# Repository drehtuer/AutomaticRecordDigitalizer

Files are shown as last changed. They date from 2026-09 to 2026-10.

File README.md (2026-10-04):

# AutomaticRecordDigitalizer






A DIY machine that digitises a vinyl record collection unattended: it takes a record from a magazine, puts it on a Technics-style turntable (an Omnitronic DD 3120), cues the stylus, records the side, flips the record, records the other side, and puts it back — 10 to 20 records per eight-hour run, a full 24-slot magazine over a weekend, with a photo of both labels for the tags. Records are brushed by hand before they go into the magazine.

The project exists because the cheap way of doing this, a second-hand stacking record changer, drops records onto each other and the recordings show it. Here nothing ever touches a record except a vacuum cup on the label, the slot it stands in, and the turntable mat.

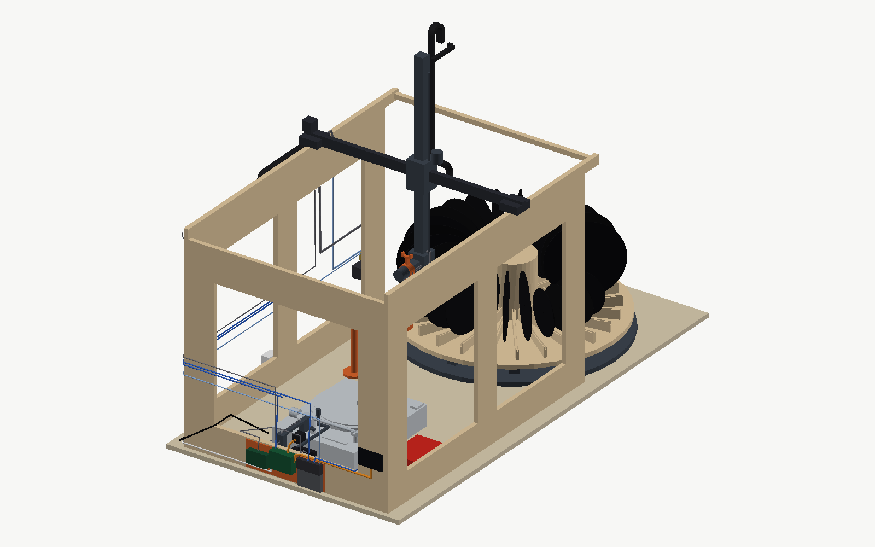
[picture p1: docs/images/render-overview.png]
The machine, rendered from the CAD model: the carousel of records on the left, the gantry on its wooden frame, the turntable on the right, the electronics on the outside of the panels


## Status

Concept design finished and reviewed in September 2026; first parametric CAD in place, with the whole cycle passing a scripted collision check. Nothing has been bought or printed yet. [docs/07-status-and-next-steps.md](docs/07-status-and-next-steps.md) records exactly where the project stands, what is already on hand, and what to do first.

## What is in this repository

[cad-model.html](cad-model.html) is the machine in the browser: orbit and zoom it, play the cycle for a 12", a 10" or a 7" record, or jump to any of the fourteen steps. Both halves come from the parametric model — the geometry from `python -m cad.export_web`, the motion from the planner's own keyframes in `cad/cycle.json`, one cycle per record size — so it shows the machine the collision checker sweeps, moving the way it sweeps it. The carousel carries a mixed load of all three sizes, with the empty slot the loading rule asks for.

[concept-model.html](concept-model.html) is an interactive 3D model that steps through the complete operating cycle, including the B-side flip and the fault case, with every step's motion planned as real waypoints in the order the controller will use. Its geometry is its own, written during the concept phase, and predates the five corrections the CAD found: read it for the sequence, not for dimensions.

`cad/` is the parametric CadQuery model with the motion planner and the collision checker; `cad/README.md` explains how to run it, and `cad/export/` holds STEP files that open in FreeCAD, STL files of the first printed parts, and `web/` holds the glTF and the scene description the viewer loads.

`sourcing/` is the pricing pass of September 2026, re-verified on 3 October: every line of the bill of materials against live German shop pages, with product links, three ways of ordering it and a sheet for the local Baumarkt, and the corrections it forced back into the design documents.

`docs/` holds the design in detail:

| Document | Contents |
|---|---|
| [01-design-specification.md](docs/01-design-specification.md) | Mechanical layout, every subsystem, dimensions, materials |
| [02-operating-cycle.md](docs/02-operating-cycle.md) | The cycle step by step, motion-planning rules, fault handling |
| [03-electronics-and-software.md](docs/03-electronics-and-software.md) | Controller, wiring, Klipper, orchestrator, vision, web UI, recording |
| [04-bill-of-materials.md](docs/04-bill-of-materials.md) | Parts with German sources, printed-part list, cost |
| [05-design-decisions.md](docs/05-design-decisions.md) | Why the machine is the way it is, including rejected alternatives |
| [06-open-questions.md](docs/06-open-questions.md) | What has to be verified on real hardware |
| [07-status-and-next-steps.md](docs/07-status-and-next-steps.md) | Current state, parts on hand, build order |
| [08-assembly-instructions.md](docs/08-assembly-instructions.md) | Cut list, Baumarkt list, printed parts, assembly order, cable lengths |

## The machine in one paragraph

Records stand like spokes in a 24-slot carousel. A small XYZ gantry with a rotary wrist carries a vacuum cup that takes each record by its label, lifts it out of its slot, turns it flat over the deck and sets it on the spindle. The deck's own cue lever, worked by a servo, lifts the tonearm while a fork on the wrist walks it to the lead-in groove found by a camera; the platter is stopped before every needle placement and removal. After the run-out, the record goes to a ring rest where the cup lets go and re-grips the other face, both labels get photographed, and side B is recorded the same way. The record returns to its own slot and the carousel indexes to the next one. The deck's remote start/stop connector starts and stops the platter. Recording runs through a Focusrite Scarlett into a Raspberry Pi, which also runs the cameras, the web interface for the batch list, and the orchestration on top of Klipper running on a printer mainboard, with a USB relay card working the deck's remote start/stop jack and speed buttons.

## Follow-up project

Cutting the recordings into tracks, mastering, and tagging (using the label photos and the batch manifest) is deliberately out of scope until the changer has proven itself on real records.

## License

Copyright (C) 2026 drehtuer

This project is free software; you can redistribute it and/or modify it under the terms of the GNU General Public License as published by the Free Software Foundation; either version 2 of the License, or (at your option) any later version. The text of version 2 is in [LICENSE](LICENSE); the SPDX identifier is `GPL-2.0-or-later`.

It is distributed in the hope that it will be useful, but WITHOUT ANY WARRANTY; without even the implied warranty of MERCHANTABILITY or FITNESS FOR A PARTICULAR PURPOSE. See the GNU General Public License for more details.

The licence covers everything here: the CadQuery model and the planner as source code, and the design documents and the concept model as the machine's design.

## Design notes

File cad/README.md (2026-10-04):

# CAD

Parametric CadQuery model of the machine, the motion planner of the cycle, and a collision
checker that sweeps every step of the cycle against the whole machine.

```sh
pip install cadquery            # 2.4 or newer; pulls in the OpenCascade kernel
python -m cad.check_collisions  # sweep the full cycle with a 12", then the pick with a 10" and a 7"; exit 1 on any intersection
python -m cad.check_collisions --size 7   # the whole cycle with a 7"
python -m cad.assembly place regrip   # STEP of the whole machine at named poses
python -m cad.export_parts      # STL of the printed parts, STEP of the sub-assemblies
python -m cad.kinematics > cad/cycle.json  # the keyframes of the cycle for every record size, keyed "12", "10", "7" (--size 7 for one, as a bare list)
python -m cad.export_web        # glTF of every rigid body plus scene.json, for cad-model.html
python -m cad.render            # PNG views of the machine at rest into docs/images/, for the documents
python -m cad.render --animate  # the cycle for every record size as animated PNG, into docs/images/
```

Run the commands from the repository root.

## Layout

`params.py` holds every dimension in millimetres, including the deck measurements marked
MEASURE that still have to be confirmed with a ruler; the deck's outline, platter height,
spindle, arm pivot and cue-lever travel are measured. Change a number there and everything
downstream follows.

`parts/` builds the solids: `deck.py` (plinth, platter, tonearm as a rigid body pivoting about
the measured pivot, cue lever), `carousel.py` (base with roller ring, rotating disc with hub,
V-floor combs and tooth ring, records of any size as spokes), `frame.py` (plywood box, V-slot beams, flip
station on its foot), `gantry.py` (X, Y and Z carriages and the wrist with cup, camera and
fork, each in its own kinematic frame), `deck_interface.py` (cue-lever servo on its beam with
horn and yoke, the end stop, deck camera and LED bar), `electronics.py` (every board and box on the frame
at its catalogue size, the three cable chains, and the cable and hose runs as tubes along their
routes). The chains and the cables that feed them are drawn at the home pose, because their shape
changes with every move; the sweep checks the electronics and the cable runs that ride rigidly on
the column and the wrist, and does not check the chains.

`kinematics.py` is the forward kinematics (where the cup and the fork are for a carriage
position and wrist angle), the fourteen poses of the cycle, and the planner that turns two
poses into a list of keyframes: retreat, raise, ordered horizontal moves, lower, approach, with
the special plans for the station and the tonearm steps. It is the same planner the concept
model animates and the one the orchestrator will run.

`assembly.py` places the parts for a state and exports a coloured STEP. `check_collisions.py`
samples every keyframe segment (20 mm and 5° by default), rebuilds the moving parts and the
pose-dependent environment (tonearm angle and lift, carousel angle, which records are where)
and reports every intersection between the Z carriage, the wrist and the held record and
anything else, with the pose, the segment and the position. `export_parts.py` writes the STL
files for printing and the sub-assembly STEP files for FreeCAD. `export_web.py` writes every rigid body in
its rest frame as one glTF plus `scene.json`, the constants the viewer in `cad-model.html` needs to assemble
and animate them; the viewer restates no dimension of its own. `render.py` tessellates the machine and rasterises
orthographic views through a depth buffer with nothing but numpy, since the container has no renderer and
no browser; the pictures in the documents come from it, and with `--animate` it samples the planner's
keyframes on the web viewer's own timeline and places every rest-frame part exactly as the viewer does
(checked: the same bounding boxes as `Machine` to the last millimetre), writing one animated PNG per size.

`export/` holds generated files. They are committed at reviewed states so the STEP files can
be opened without running anything; regenerate them after changing `params.py`.

## Coordinate system

X along the bench from the carousel towards the deck, Y across the bench with +Y towards the
front, Z up. Origin on the bench top, 200 mm left of the flip station post, on the machine's
centreline. A carriage state is the centre of the Z carriage block; the wrist pivot sits
`WRIST_X` further along +X. Wrist angle `phi` is a right-hand rotation about +X: 0 is the arm
hanging with the cup facing −Y, +90 is the cup facing down, −90 the cup facing up, 180 the arm
pointing up with the fork pointing down.

## Record sizes

Every record stands with its centre at `CAR_REC_R`, whatever its diameter, because the slot floor
of each comb is a V with its apex there; `carousel.record_z(r)` gives the centre height for a
radius. `Machine(record_r)` builds the machine with a record of that radius in slot 0, on the cup,
on the platter and on the ring, with 12" records in the other slots, and `kinematics.full_cycle(r)`
plans the cycle for it: only the pick and the return move. `Machine(load=carousel.DEMO_LOAD)` fills the
other slots with the mixed load the pictures and the viewer show (three 10", four 7", one empty slot for
the loading rule, 12" in the rest); the checker never uses it. The neighbour that matters is slot 1,
the spoke on the front side of the pick, the one the wrist descends beside; `Machine(record_r,
neighbour_r)` sets it (None leaves it empty). The checker sweeps the whole cycle with a 12" and then
the pick, the carry away from the slot and the return with a 10" beside a 12" and a 7" beside a 10",
the largest neighbours the loading rule allows; `--size 7 --neighbour 12 --poses pick` shows why the
rule exists.

## Fidelity

This is a layout model: every part has its true envelope, position and travel, the records are
real discs with holes, and the tonearm pivots about the measured point. It is not yet a print
model. The printed parts that exist as separate functions (`comb`, `hub`, `roller_bracket`,
`ring_rest`, `fork`) have their functional features; the rest of the printed parts are still
envelopes inside their sub-assembly and get detailed as the build reaches them.

## What the checker found so far

Running the checker on the first version of this model found five real problems that the
concept model had not shown, and they are fixed here: the wrist camera on the hub side of the
arm sat where the gap between spokes narrows (moved to the outer side and higher up the arm);
the cup bracket reached below the cup and met the spindle tip (raised); the end-stop pin stood
inside a 12" record's outline (moved from 60 to 45 mm from the pivot); the fork pointed through
the rear panel at the re-grip pose (shortened from 100 to 55 mm, frame widened to 86 cm); and the
swing to B-up over the deck pushed the record into the front panel (the station plan now swings
the record to vertical before moving Y). Adding the record sizes found a sixth: picking a 7" beside
a 12" puts the wrist hub 18 mm and the column's foot 7 mm into the neighbour, which no change to
the slot can fix and became the loading rule in the design decisions. At 20 mm / 5° sampling the
cycle runs with zero intersections for every size.

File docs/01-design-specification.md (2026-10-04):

# Design specification

This document describes the machine as it stands after the concept review. Dimensions are the ones used in the concept model and are good to a centimetre; the CAD phase fixes them to the millimetre. The coordinate system is the machine's: X runs along the bench from the carousel towards the deck, Y runs across the bench (positive towards the front), Z is up. The origin is at the bench top under the flip station.

## Overview and footprint

The bench is about 190 × 100 cm. From left to right it carries the carousel magazine (Ø 86 cm, standing free on the bench), then the frame (121 × 88 × 83 cm over the panels) that spans the flip station and the turntable. The gantry rides on top of the frame; its Z column rises to about 135 cm when fully raised, so the machine wants a metre and a half of headroom.

The frame's left end is open and its X beams overhang it by 8 cm so that the gantry can reach the carousel's pick slot, which is the only point where the two halves of the machine meet. The carousel can be lifted off the bench for loading without touching the frame.

## Frame

The frame is a glued box of 18 mm OSB 3: two side panels at Y = ±43 cm and one end panel at the deck end, each cut as a frame around a large window so the interior stays open and reachable. The panels give the racking stiffness; there are no diagonals, and the only corner posts are a steel angle down each inside corner where the side panels meet the end panel, because a screw into an OSB edge holds poorly. A 2040 V-slot extrusion is bolted along the top edge of each side panel and is the X axis: the carriages run on Delrin V-wheels in the slot, as on a hobby printer. One 2020 tie across the open end keeps the two beams parallel. Brackets for the cue-lever servo, the deck camera and the LED bar fix directly to the panels' inner faces, on M4 T-nuts wherever a part has to come off again.

The electronics are not boxed: the controller board and its supply mount on the outside of the rear panel under the X beam, the pump and valve on the same panel near the open end, and the Pi with its USB devices on the outside of the deck-end panel. The flip station's post stands on a printed foot on the bench.

## Gantry

The gantry is a Cartesian XYZ with one rotary axis:

| Axis | Mechanism | Travel | Notes |
|---|---|---|---|
| X | GT2 belt, NEMA17, Delrin wheels on 2040 V-slot beams | ≈ 80 cm | From the carousel pick slot to the tonearm rest |
| Y | GT2 belt, NEMA17, Delrin wheels on a 2040 V-slot cross beam | ≈ 63 cm | The concept assumed 45 cm; the planner's re-grip poses reach from −34 cm to +28.5 cm. The 94 cm cross beam gives about 70 cm; the frame is 86 cm wide so the fork clears the rear panel at the re-grip pose |
| Z | T8 lead screw, NEMA17, moving column on an MGN12 rail | ≈ 60 cm | Column slides through a guide on the cross beam; self-locking; the one axis that keeps a linear rail |
| Wrist | NEMA17 with ≈ 5:1 planetary gearbox, Hall home sensor | −90° … 180° | Axis parallel to X |

The Z axis is a moving column rather than a fixed tower: the 76 cm rail is part of the carriage and slides up through a guide block on the cross beam, so when the carriage is raised nothing hangs below it. Every X move happens at travel height and clears the deck and the station by construction. The lead screw is self-locking, so a power loss leaves the record where it is.

The wrist sits on a 9 cm outrigger beside the column so the arm can swing without meeting it. It carries three things: the vacuum arm (22 cm, with the cup on its end pointing perpendicular to the arm), the wrist camera looking along the cup's axis, mounted on the outer (+X) side of the arm 11 cm up from the cup, and the finger-lift fork on the opposite side of the hub, 5.5 cm long, which points down when the arm points up. The cup bracket does not reach below the cup, so the spindle tip, which enters the hollow bellows cup when a record is released over the spindle, meets nothing.

## Gripper

The gripper is a single 40 mm bellows vacuum cup on the label area, fed by a 12 V diaphragm pump through a solenoid release valve, with a pressure sensor on the line that confirms a seal before any move and aborts a move if the seal is lost. The label area is the one thing every record has in common, so the cup handles 12", 10" and 7" records and shaped discs alike; 7" singles with the large jukebox hole are out of scope. What the cup can hold and what the carousel can present are not the same set: the magazine locates a record by its round edge, so a shaped picture disc, or one whose outline is not centred on its hole, is placed on the platter by hand and the machine does the rest (see the operating cycle).

The cup's bellows give about 5 mm of compliance, which is what lets the cup land on a spoke standing slightly off its nominal position. At the pick position the cup stops 8 mm short of the record's face and makes the last 8 mm as a slow approach; the gap between spoke faces at the arm's radius is 65 mm and the cup-to-arm-back assembly is 48 mm, so the approach and a 9 mm margin use the rest.

## Carousel magazine

The magazine is a horizontal disc with 24 radial slots at 15° pitch. Records stand vertically in the slots like spokes, each in a 5 mm slot on top of a printed comb. The floor of that slot is a shallow V, sloping 5° each way from an apex 26 cm from the axis, so a record of any diameter rolls to the apex and stands with its centre on the same vertical line: 12", 10" and 7" records all sit at the same radius, and only the height of the centre differs, by the record's radius. The pick is therefore the same X and Y for every size, and the machine takes the height from the size in the batch manifest. At that radius the gap between neighbouring spokes is about 6.5 cm face to face, enough for the 5 cm gripper assembly to descend beside a record. A 10" is picked 25 mm lower between the same neighbours, through the same gap. A 7" is picked 62 mm lower, and there the gap runs out: the wrist hub, the outrigger and the foot of the column sit 22 cm above the cup and are wider than the gap at the radius where they descend, so they have to stay above the top edge of the neighbouring spoke on the front side, the side the wrist hangs on. Beside a 12" neighbour a 7" pick puts the hub 18 mm and the column's foot 7 mm below that edge. So the slot on a 7"'s front side holds a 7", a 10" or nothing, a rule the manifest editor enforces; a run of 7"s costs one empty slot at its front end. There is no rim: the V does the locating, and a wall tall enough to touch every size at its own centre would stand in the way of a record being carried past at travel height.

The disc is 18 mm MDF cut roughly round and is nothing but a floor. It rolls on ten identical printed brackets, each holding a 608 bearing, arranged on a 72 cm circle, and is located by a 6005 bearing on a stub shaft at the centre. A printed GT2 tooth ring in eight dovetailed segments on the disc's underside is driven by a NEMA17 with a 20-tooth pulley, about 34:1 at the ring and about 170:1 with the motor's 5:1 gearbox, and an optical sensor reads a home mark; one slot index is therefore repeatable to a fraction of a millimetre at the rim. The 24 slot combs plug into a printed centre hub, which carries the angular positions, and are screwed to the disc at their outer ends, so the wood never has to be cut precisely.

Each record returns to the slot it came from, so the magazine is both infeed and outfeed, records never touch each other, and pick and return happen at one fixed position: the slot that points along X towards the deck.

## Flip and photo station

A ring rest on a post 12 cm behind the machine's centreline, at X = 20 cm, Z = 30 cm: a printed ring of 100 mm mean diameter and 6 mm section, so it contacts a record between 44 and 56 mm from its centre — the edge of the label, where the record is stiffest — with a 3 mm rubber O-ring in a groove on top that the record actually rests on. It holds a 7" with 32 mm of overhang, leaves 16 mm between the cup and its inner edge, and its 60° opening towards the front, 44 mm wide at the inner edge, passes the 24 mm arm with 10 mm a side. That the ring touches a 12" just outside the label is accepted: the O-ring is soft, and stability matters more than the last millimetre of dead wax. The station is deliberately off the centreline so that a vertical record travelling along X at travel height passes beside it.

## Turntable interface

The deck is an Omnitronic DD 3120: a Technics-type direct drive, 44.9 × 35.1 × 8.6 cm as measured, from the feet to the top of the case, with the platter standing 1.8 cm above that, with a manual cue lever, a remote start/stop connector, a pitch output, 33/45/78 rpm with quartz lock and ±10/±20 % pitch range, and no auto-return. Measured on the deck: the spindle sits 17.9 cm from the left edge and 17.4 cm from the rear edge; the arm pivot, the screw on top of the bearing, is 6.95 cm from the right edge and 9.35 cm from the rear, which puts it 20.05 cm to the right of and 8.05 cm behind the spindle (pivot-to-spindle 21.6 cm, a 14 mm overhang on a 23 cm effective length); the top of the cue lever is 4 cm inside the right edge and travels front to back, from 14.6 cm from the rear edge with the arm down to 12.2 cm with the arm lifted, 24 mm towards the rear. Still from a top-down photo (`images/dd-3120-top.jpg`) and to be confirmed with a ruler: the arm rest is about half a centimetre left of and 21 cm in front of the pivot; start/stop and the speed buttons are at the front left, the power knob at the left, the pitch fader at the right in front of the arm, and the deck's own red strobe LED shines on the platter rim at the front left. The platter rim carries four rows of strobe dots.

The felt DJ slipmat in the photo should be replaced by a rubber or cork mat for digitising: a slipmat is made to let the record slip, and it also holds static and dust. (A Stanton T.92 USB is also available but has no cue lever, which would bring back a separate arm-lift mechanism; it stays the spare.) The cartridge is an Ortofon DJ S, a spherical DJ stylus tracking at about 3 g, robust against the kind of handling this machine does; an elliptical stylus can be swapped in for a final archive pass once the machine is trusted. The machine touches the deck in four places, none of them modifications:

Start and stop go through the deck's own remote start/stop connector, a 6.3 mm jack made for the fader-start feature of older mixers and hi-fi systems, which started the deck when the fader came up: it expects a contact closure and does nothing but start and stop the platter (speed is chosen with the buttons). One channel of the Conrad 393905 USB relay card (already on hand, driven from the Pi) on a 6.3 mm plug does it, with no wire soldered inside the deck. The 33 and 45 buttons are momentary switches and are pressed by two more channels of the same card wired across the switch contacts inside the deck; a relay is a dry contact, so polarity and the switch's voltage do not matter.

The cue lever is worked by an MG996R servo that hangs over it from a beam off the deck-end panel of the frame. The lever's top travels 24 mm front to back, so a rod pushing along X from the panel cannot move it; the servo's shaft stands vertical 28 mm to the right of the lever, and its horn carries a yoke that straddles the lever's top and takes it both ways, about 25° of horn either side of the middle. The lever is 4 cm from the deck's right edge, so the servo sits over the edge of the case, to the right of the arm base and outside the arm's swing. A bar from a foot on the same panel runs in front of the lever, under the arm, and carries a soft-sleeved end-stop pin standing in the arm tube's path 45 mm from the pivot, so the arm cannot swing past a stylus radius of roughly 53 mm: the stylus physically cannot reach the label. At 45 mm the pin stands outside a 12" record's outline; at the 60 mm first drawn it stood under the record's edge.

The tonearm is moved only while the cue lever holds it up, by the fork straddling the headshell's finger lift with prongs fore and aft of it. The fork never carries the arm's weight.

The arm rest clip stays open.

## Cleaning

There is no cleaning module. Records are brushed by hand before they go into the carousel; a brush pass takes a minute per record and is the right moment to look each one over anyway. A frame-mounted brush with a dust edge was designed and dropped as a simplification; the decision log has the details, and the rear panel has room for it if it ever comes back.

## Cameras and light

The wrist camera (a USB webcam, a Logitech C270) sits on the outer side of the wrist arm, 11 cm up from the cup, looking along the cup axis. With the cup pointing down it looks straight down, and that is where it works: hovering over the platter after a record is placed it photographs the label that is facing up, finds the centre (the spindle is in the hole) and measures the lead-in and run-out radii; over the ring rest it photographs the other label before the re-grip. Both label photographs come from it, each taken face-on with nothing in the way. At the carousel it does not look at the record: inside the 65 mm gap between spokes there is no room for a camera at a usable distance, and none is needed, because a record that has rolled to the apex of its comb's V has its centre within a millimetre of a known position, which the cup's bellows and the spindle tip absorb.

The deck camera (Pi Camera Module 3) is mounted low on the deck-end panel at platter height, facing the headshell across the platter from 20 to 40 cm. It sees the stylus in profile, the groove bands edge-on and the strobe dots on the platter rim. It tracks the headshell to locate the arm wherever a side ended, confirms the stylus landed on the lead-in, watches for the run-out and for skips, and reads the platter speed.

An LED bar beside the deck camera has two modes: pulsed at 50.000 Hz from the controller's crystal it is a strobe that makes the rim dots (or a printed strobe ring on a deck without dots) show the speed error as a drift; run continuously it is a low-angle raking light that makes the grooves and the stylus contact visible.

## Materials and printing

Printed parts are PETG for structure and TPU wherever a record is touched: the cup lip if not bought, the fork lining, the end-stop sleeve; the ring rest carries a bought rubber O-ring instead. Bought parts are everything long, stiff or precise: extrusion, the Z rail, screws, bearings, motors, electronics; a used 3D printer is the intended source for most of the motion parts. Plywood is used for the frame panels, the bench top, the carousel disc and its base plate, and never for anything whose position matters.

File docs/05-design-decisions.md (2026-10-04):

# Design decisions

The machine took its shape through a review of a series of concept models. This document records what was decided, why, and what was rejected, so the reasoning survives into the CAD and software phases.

## No stacking changer

A second-hand automatic changer costs a fraction of this machine and needs no building. It was rejected because it drops each record onto the previous one, and a record playing on a stack of records is tilted, poorly supported and audibly distorted. Every other decision follows from the requirement that a record is never supported by anything but the mat, and never touched except on its label.

## Gantry, not an arm

A Cartesian gantry with one rotary wrist was chosen over an articulated arm. Linear axes give repeatable positioning for free, a 3D-printed jointed arm is hard to make stiff, and a gantry turns the whole build into a printer-shaped problem with a printer's toolchain. The wrist is the only joint and it does two jobs: turning the record from vertical to horizontal and flipping it for side B.

## Vacuum cup on the label

Early concepts gripped the rim with three fingers. That failed on two requirements: 10" and 7" records have a different rim, and shaped records ("sawblades") have no usable rim at all. The label area is the one feature common to every record, so the gripper is a single vacuum cup on the label. A label-pinch gripper (a pin through the centre hole and a jaw on the label) was considered as an alternative that needs no pump and cannot drop a record when power fails; it was set aside because the vacuum cup is simpler and a sensor on the line gives a positive confirmation of grip (the switch first drawn became a pressure sensor; see below). 7" singles with the large jukebox hole are excluded.

## Round magazine instead of racks

The first layouts had a leaning queue for infeed and a slotted rack for outfeed, later a stepper-driven follower and a slotted comb. Each had a flaw: the queue put records face to face under pressure, the slotted rack could not accept a record with the gripper beside it at 20 mm pitch, and both needed the gantry to travel over 1.5 m. A round magazine with records as spokes solves all of it: the gap between neighbours at the label is 6.5 cm, pick and return are at one fixed position, each record goes back into its own slot, records never touch, and the X travel halved. The price is a diameter of 86 cm.

## Every size at one radius: the V floor

The concept placed records with their outer edge against a rim ring, so that every size would sit at the same outer radius and a 7" would stand where the gap between spokes is wider. The first CAD drew the ring and never used it: a ring at one height meets a 12", a 10" and a 7" at three different chords, so each size would have come to rest at its own radius, and the pick was in fact drawn for a 12" alone, standing on the disc through its comb. A wall tall enough to touch every size at its own centre, 17 cm above the disc, would stand in the way of the carried record, whose lower edge passes 7 cm above the disc at travel height. The rim is gone. Instead the floor of each comb's slot is a shallow V, 5° each way, with its apex 26 cm from the axis: a record of any diameter rolls to the apex and stands with its centre on one vertical line, and only its centre height differs, by its radius. The pick and the return are the same X and Y for every size, with the height from the manifest's size; the planner and the collision sweep take the size as a parameter, and the sweep runs the 10" and the 7" through the pick, the carry away from the slot and the return, between 12" neighbours. The 7" gives up the wider gap the rim would have given it, and the sweep showed where that bites; the next entry is the answer.

## A 7" wants a 7", a 10" or nothing on its front side

The first sweep with a 7" in the pick slot and 12" records around it found the wrist hub 18 mm and the foot of the column 7 mm inside the neighbouring spoke on the front side, the side the wrist hangs on. The geometry is simple: everything at the wrist pivot sits 22 cm above the cup, a 12" neighbour's edge reaches 15 cm above its own centre, and a 7" is picked 62 mm deeper than a 12", so the pivot hardware ends up 8 mm below that edge and its own height does the rest; at the radius where the column's foot descends the gap between spokes is 42 mm, which no column with a lead screw beside it fits. Nothing passive in the slot helps, because a floor that lifts a small disc lifts a large one at least as much. A 3 cm longer arm would lift the hub clear but pushes the re-grip pose past the Y travel unless the station moves 3 cm towards the centreline, with everything that follows from that; a hub small enough to fit would have no room for its bearings; a saddle dropped into the slot under each 7" would work until someone forgot one. The rule costs nothing: the slot on a 7"'s front side holds a 7", a 10" or nothing, so a run of 7"s costs one empty slot at its front end, and the manifest editor refuses a batch that breaks it. The collision sweep runs the 7" with a 10" in front of it, the largest neighbour the rule allows, and `python -m cad.check_collisions --size 7 --neighbour 12 --poses pick` reproduces the case it forbids. A 10" needs no rule: beside a 12" it keeps 19 mm at the hub and 32 at the column's foot.

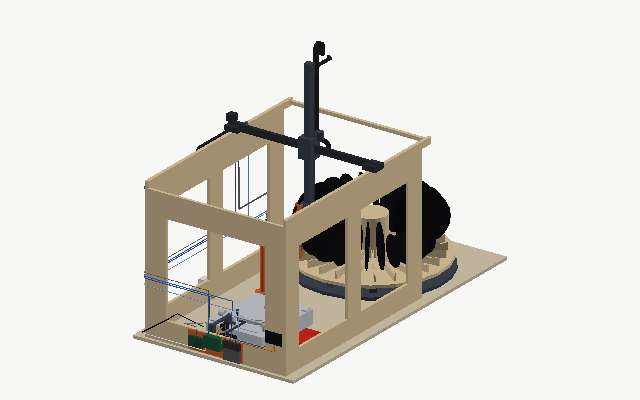
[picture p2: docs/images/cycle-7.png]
The cycle for a 7" record, rendered from the model: the wrist descends 62 mm deeper into the carousel than for a 12", beside the 10" the loading rule allows there


## Shaped and off-centre discs are placed by hand

The V locates a record by its round edge, and the pick assumes the label at the centre of that circle. A shaped picture disc has no round edge to roll on, and a disc whose outline is not centred on its hole stands at a height the machine cannot know; the cup could hold either by its label, but the machine could not find the label, and one look with the wrist camera cannot help, because there is no room for it inside the gap. Rather than an adapter or a special slot, the manifest has a "by hand" line: the gantry parks, the user lays the record on the spindle, and the machine records the side, photographs and measures it, and waits for the user again at the flip and at the end. The cycle is unchanged, the carousel is untouched, and a mode the machine needs anyway for a record too precious to be picked covers every outline the V cannot.

## Wrist axis along X

With the pick slot pointing along X, the record's face is normal to Y and the cup must approach along Y, so the wrist rotates about X and the Y axis does real work: it carries the cup onto and off the spoke and it reaches 22 cm either side of the station ring for the two station poses. This set the Y travel at about 45 cm.

## Flip via a passive ring rest

A cup on one face can never place the record with that face down; somewhere the cup must change sides. Two ways were considered: a two-cup yoke that flips in the air, and a passive ring rest that the record is set down on by its label so the cup can re-grip from the other side. The ring won because it has no moving parts, it is also the best place to photograph label B, and it costs twenty seconds per side. It was moved 12 cm off the centreline once the motion planning showed that a vertical record travelling along X would otherwise pass through it.

## Moving Z column

The first gantry had a fixed Z tower hanging from the cross beam, and it swept through the brush, the platter and the station on every X move. Replacing it with a column that slides up through a guide means nothing hangs below the carriage when it is raised, and every X move happens at a travel height that clears everything by construction.

## Fork on the wrist, opposite the arm

Hanging the finger-lift fork from the carriage either dipped it into the carousel during a pick or parked the carriage a few centimetres above the tonearm while cueing. Mounting it on the wrist hub opposite the vacuum arm means it points down exactly when the arm points up, shares the cup's Y position, and keeps the carriage well above the arm.

## The deck's own cue lever does all lifting

The turntable has a manual cue lever. A servo on a frame bracket works it, so every lift and lower of the tonearm happens on the deck's damped mechanism, and the fork only ever moves the arm sideways while it is floating. The arm cannot be dropped by the machine. The servo was first drawn at the end panel with a pusher rod along X; measuring the deck showed the lever's top travelling 24 mm front to back, which a rod from that side cannot push, so the servo now hangs over the lever on a beam from the panel, shaft vertical, with a yoke on its horn around the lever's top. The yoke moves the lever in both directions, so it does not matter whether the lever holds its position by itself. The platter is stopped before every stylus placement and removal, as it would be by a careful person; the lead-in silence absorbs the spin-up.

## Inner end stop

The cue-servo bracket initially collided with the arm's inner swing. That collision became a feature: a soft-sleeved pin on the bracket stands in the arm tube's path just past the run-out radius, so whatever the software does, the stylus cannot reach the label.

## Omnitronic DD 3120, not the Stanton T.92

Two decks were available. The Omnitronic has a cue lever, a remote start/stop jack and a pitch output; the Stanton has none of these and a built-in USB converter that is not wanted. The cue lever alone decides it: without one, the machine would need its own damped arm lift, which is the part most likely to damage a record. The remote jack (6.3 mm, the fader-start input of older mixers and hi-fi systems, start/stop only) is a bonus that removes all soldering on the start/stop switch. The cue lever turned out to sit at the front-right of the arm base, 4 cm from the deck's right edge, which put the cue servo on a short beam from the frame's end panel instead of an outrigger from the rear.

## No automatic skip recovery

A skip is detected by audio and by camera at once. The response is to lift the arm via the cue lever within half a second, stop the platter, pause the batch and notify. Re-cueing automatically was rejected because a record that skipped once will usually skip again at the same place, and an unattended retry loop grinding a stylus into a scratch is the one thing the machine must never do.

## Two cameras, placed by what they need to see

An overhead camera cannot see a label or hole past the gripper. So the label camera rides on the wrist looking along the cup's axis: with the cup pointing down over the platter or the ring rest it looks straight down at whichever label is facing up, with nothing in the way, and measures the groove radii there. The deck camera sits low at platter height facing the headshell, where it sees the stylus in profile, the groove bands edge-on and the strobe dots on the rim. A rail-top camera above the deck was tried and moved for that reason. The wrist camera was first meant to look at the record's face inside the carousel gap as well; the CAD showed there is no room for a camera at a usable distance inside a 65 mm gap, and the V floor of the comb makes the record's position known well enough that no look is needed there.

## 33/45 by the deck's buttons, not by resampling

Recording everything at one speed and resampling later was rejected because the phono stage applies RIAA equalisation at fixed frequencies; a record played at the wrong speed is equalised wrongly and resampling does not undo it. The deck's 33 and 45 buttons are momentary switches, so two relay channels across the switches and a manifest column solve it properly; relays rather than optocouplers because a dry contact needs no knowledge of the switch's polarity or voltage, and the Conrad 393905 USB relay card already on hand supplies them from the Pi.

## LED strobe for speed, not camera frame rate

The camera cannot imitate a 50 Hz neon strobe, but an LED pulsed at 50.000 Hz from the controller's crystal makes the deck's dot rows, or a printed strobe ring on a deck without them, show the speed error as a drift the camera can measure. It works on any turntable, and the same LED run continuously is a raking light that shows the grooves for cueing and stylus checks. The measured speed and wow are logged with each recording rather than corrected live.

## No brush

A frame-mounted brush with a servo arm, a dust edge and a slide-out tray was designed in full and then dropped. Brushing by hand before loading takes a minute per record, is a natural moment to inspect each one, and removes a motor, a bracket, a cycle step and a source of dust inside the machine. The rear panel keeps room for the module.

## Manual deck, not an automatic one

A fully automatic turntable would have removed the cue servo, the fork, the end stop and most of the deck camera's job, and was proposed as the biggest available simplification. It was rejected because the collection contains records an automatic deck cannot play: sides with several locked grooves, sides cut from the inside out, and records with non-standard start and end positions. Those need a machine that decides where the stylus goes and when it leaves, which is why the manual DD 3120, the fork, and both cameras stay.

## V-slot instead of linear rails

X and Y run on 2040 V-slot with Delrin wheels, as on a hobby printer, instead of MGN rails. The accuracy needed at the cup is set by the hole camera and the spindle tip, well within what V-wheels give, and the change saves about a hundred euros and makes alignment easier. The Z column keeps a rail because it carries the record vertically and its guide block must not rattle.

## A used printer as parts donor

Most of the motion parts (steppers, PSU, belts, pulleys, wheels, a lead screw, end-stops, a Klipper-capable board) come cheapest as a used 3D printer; a CR-10 class machine is the best fit because of its long extrusions and lead screws. Only the two long X beams and the Z rail are bought new.

## Wooden frame, extrusion beams

A full aluminium extrusion frame was replaced by a glued box of 18 mm sheet material with 2040 V-slot extrusion only where the X axis needs a straight, adjustable running surface. The panels give more racking stiffness than a lattice with diagonals, the interior stays open, brackets fix straight to the panels, and extrusion drops from ten metres to four. Cost is about the same; the choice is about the tools the builder prefers.

The panels are OSB 3, decided on 4 October 2026. Birch multiplex was the plan, but the only birch sheet large enough for all three panels in one piece, 3000 × 1500, costs 222,80 € and is a four-to-five-week store order, while two 2500 × 1250 sheets of OSB cost 62,18 € and are on the shelf. OSB is as stiff as the box needs; what it does badly is hold a screw in its edge, hold a wood screw that is taken out and put back, and resist a bolt head pulling into its strands. Each of those gets metal instead of wood: a 25 × 25 × 3 steel angle the full height of each inside corner, M4 T-nuts for every part that comes off again, and penny washers under the M5 beam bolts, together about 25 €. Birch was rejected for price and lead time, and the maritime-pine and birch-faced alternatives because they cost three times as much as OSB for a smoother face nothing needs. The two carousel discs are MDF, which is flat, and flatness is the only thing the discs need.

## Vacuum sensing on the Pi, the grip check in the orchestrator

The concept put a vacuum switch on a controller end-stop input so that `GRIP` could wait for it inside Klipper and a lost seal would abort inside the motion queue. Pricing it found that an industrial vacuum switch starts at about 95 €, more than the rest of the sensing together, while an Adafruit MPRLS pressure breakout costs 31 € — but is an I²C device that can only talk to the Pi. Three ways were laid out: the MPRLS alone and accept the latency; the MPRLS for the reading plus a cheap switch kept as a Klipper interlock; or the switch as drawn. The first was chosen. The seal check is an orchestrator step and the abort is one poll interval plus one Moonraker round trip, under a tenth of a second; a record being carried is never more than a few centimetres above a surface made to receive it, so that latency does not decide anything. In exchange the machine gets a pressure number rather than a contact, which tells a weak seal from none, can be logged with every side, and leaves one sensor and one tee in the cup line instead of two.

## Ring rest at the label's edge

The concept wanted the ring rest to touch nothing but the label, an annulus of 70 to 86 mm diameter; the first CAD drew the same numbers as a radius, which put the ring on the grooves and left a 7" balanced on its outermost two millimetres. Neither survived. The ring is now 100 mm in mean diameter with a 6 mm section, contacting a record between 44 and 56 mm from its centre: the edge of the label, the stiffest part of any record, with a 3 mm rubber O-ring on top for grip. Touching a 12" a few millimetres outside its label was accepted for the sake of stability and of the 7", which now overhangs the ring by 32 mm instead of 2. The size is bounded below by the cup, which needs 16 mm to the ring's inner edge and a 44 mm gap for the arm, and above by the 7".

## The flip stays, with a one-side mode as the fallback

An alternative was weighed on 14 September: no flip at all. Each run would record one side of every record in the magazine, the user would turn the records between runs, and the magazine would be made larger to keep a run long. What it removes is real: the ring rest and its three prints, four of the fourteen steps and three of the planner's four special plans, the wrist's cup-up range, and above all the two handling steps where a record is set down and picked up again with nothing to centre it. On the platter the spindle centres the record; on the ring nothing does, so the re-grip depends on the wrist camera finding the hole, which makes it the most vision-dependent step in the machine and the one with the most open questions still against it. What it costs is half the autonomy: a 24-record batch becomes two runs of 4.5 to 10.5 hours with a visit between them instead of one unattended run of 10 to 22, and the 45 seconds it saves per record are noise against a 25 to 55 minute record. The frame does not shrink either, because its 86 cm width is also what clears the carousel's base plate at the open end.

Two parts of the alternative do not survive the geometry. Turning a round magazine through 180° presents the same faces: indexing the carousel is already a rotation about its axis and never changes which face a record shows at the pick, so the user would turn every record in its slot by hand, about two minutes for 24, and needs nothing built for it. And a larger magazine is the hard part rather than the easy one: 48 slots at the present gap is a 1.7 m carousel, halving the pitch closes the 65 mm gap to 32, which nothing on the wrist fits through, and a straight rack was rejected in the concept for the same arithmetic. A magazine that flips all its records in one move would have to be straight cassettes of parallel slots on an indexing table, a different machine.

So the flip station stays: it costs almost nothing, its geometry is swept clean, and its removal buys little on paper. What the alternative does buy is a fallback, and that is taken: the batch manifest gets a one-side mode that skips steps 9 to 12, records one side of every record and returns it, and leaves the turning to the user between runs. It costs no hardware, it is the mode the machine runs in anyway while the re-grip is being commissioned, and it makes the decision about the flip one for the first records rather than for paper: if the re-grip proves unreliable, the machine still digitises. `06-open-questions.md` has the measurement that decides it.

## Electronics on the frame, not in a box

The concept put the Pi, the controller, the relay card and the pump in a box under the flip station, with the station's post standing on it. At 260 × 180 × 90 mm the box could not hold the Octopus and the 150 W supply side by side, let alone the rest; and the deck camera's ribbon would have run over a metre from it. Instead the parts mount on the outside faces of the frame panels: the controller, the supply and the bucks on the rear panel just under the X beam, centred on the cable chain's fixed end, so every gantry cable climbs 25 cm rather than a metre; the pump and valve on the rear panel near the open end, on rubber mounts, as far from the deck as the frame allows; and the Pi with its USB group on the deck-end panel, where the deck camera's ribbon is 30 cm and the relay card's cables into the deck are short. The station post stands on a printed foot on the bench. The MPRLS reads the vacuum line through a tube stub rather than over a long I²C lead, because a pneumatic line does not care about length and I²C does.

## Roller ring instead of a lazy susan

The 86 cm carousel rolls on ten printed brackets with 608 bearings around a central 6005 bearing, rather than on a bought lazy-susan ring. It is cheaper, has no play in height, spreads the load, and every part of it is printable except the bearings.

## Precision where it is printed, cheapness where it is wood

The carousel disc and base plate, the frame panels and the bench top are sheet material cut to a few millimetres. Every position that matters, the slot angles, the rail line, the ring rest, is carried by a printed or bought part that registers to the wood without depending on how accurately it was cut.

## CAD in CadQuery, checked by script

The CAD is CadQuery code rather than a GUI model: every dimension is a named parameter, STEP and STL regenerate from it, and the same planner that animates the concept model produces the cycle's keyframes for a scripted collision sweep. The first sweep found five conflicts the concept model had not shown (camera in the narrowing gap, cup bracket on the spindle tip, end stop under the record's edge, fork through the rear panel, record swept into the front panel) and each became a parameter change or a planner rule. The sweep is the gate for every later change to the geometry.

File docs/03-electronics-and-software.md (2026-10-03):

# Electronics and software

The guiding idea is that the machine is a strangely shaped 3D printer. Motion runs on a printer mainboard under Klipper, which already solves homing, stepper drivers, end-stops, servos, PWM outputs and G-code macros; everything the printer world does not have (cameras, orchestration, recording, the web interface) runs in Python on a Raspberry Pi that is also Klipper's host.

## Hardware

**Controller.** Motion and machine I/O run on Klipper MCU firmware; two board options exist. The bought one is a BIGTREETECH Octopus V1.1 with five TMC2209 drivers (X, Y, Z, wrist, carousel index) carrying everything: its servo header drives the cue-lever servo, its fan and heater MOSFET outputs drive the vacuum pump, the release valve and the LED bar (the LED output must be a real PWM pin so the strobe can run at 50.000 Hz), and its end-stop inputs take the axis end-stops, the wrist Hall sensor and the carousel home sensor. Vacuum sensing is not on the controller at all: it is an Adafruit MPRLS pressure breakout on the Pi's I²C bus, read by the orchestrator, for the reasons under Sensors. The cheaper one, if the donor printer brings a Klipper-capable 32-bit board, uses that board's four drivers for X, Y, Z and the wrist, and a Raspberry Pi Pico (RP2040, a few euros, fully supported by Klipper) as a second MCU for the rest: the carousel stepper through one TMC2209 stick on a small breakout, the cue-lever servo, the LED bar's PWM, the pump and valve through MOSFETs, and the sensors. Klipper runs multi-MCU setups natively. The NXP MIMXRT1010-EVK on hand was considered for the second-MCU role and ruled out: Klipper's i.MX RT port covers the RT1062/1064 (Teensy 4) but not the RT1011. Either way a 24 V 150 W supply feeds the board, a 24 → 5 V buck feeds the servo and nothing else, and a 24 → 12 V buck feeds the pump, the valve and the LED bar, which are 12 V parts on a 24 V machine.

**Computer.** Raspberry Pi 4 Model B rev 1.1, 2 GB, already on hand — two of them, the second a cold spare. It runs Klipper's host process, Moonraker, the orchestrator, the vision code, the web interface and the audio capture. The Scarlett connects over USB; second-generation and later Scarletts are USB class compliant and need no driver on Linux.

Three things follow from the board rather than from choice. It has one CSI port instead of two, so the deck camera is the only ribbon camera and the wrist camera takes the USB branch described below, which this document already treated as the simpler option; the CSI-to-HDMI extender leaves the bill of materials entirely. It gives roughly two to two and a half times less CPU than a Pi 5, which the workload absorbs, because the only sustained vision load is the deck camera tracking the headshell inside a known region of interest: keep those frames downscaled to about 640 × 480 at 10 to 15 fps, and process the 12 MP label photographs one at a time rather than holding several full-resolution frames at once, which is also what 2 GB of RAM allows.

Everything that carries data hangs off a self-powered USB 3.0 hub — the Scarlett, the SSD, the wrist camera and the relay card — not off the Pi directly: a Pi 4 budgets only about 1.2 A across all four of its ports, and this machine runs unattended for a weekend, where a brown-out in the middle of a side is a lost recording. Every device gets a udev rule pinning its name, so `/dev/video*` and the ALSA card index do not shuffle across reboots and the orchestrator can address them by name. Two rev 1.1 quirks: the board refuses power from e-marked USB-C cables, so it wants the official supply or a plain cable, and its SD-card voltage regulator sits on the underside next to the slot where it is easy to knock off, so the card is set up once and left alone. Mounted in the open on the frame it still needs cooling under sustained vision load, so it sits in an Armor-type aluminium shell with twin 5 V fans. The shell cools the CPU, the RAM and the USB chip passively, the fans add headroom, it leaves the CSI and DSI connectors free, and the fans take 5 V and ground from the header, so no GPIO.

**Cameras.** One Pi Camera Module 3 for the deck, on the Pi's single CSI port with a 500 mm ribbon. The wrist camera rides on the gantry, so its cable runs through 1.5 m of cable chain; it is a USB webcam, which is simpler than carrying a ribbon signal that far and adequate for the job. The Pi reads it, so its cable starts at the hub in the Pi group on the deck-end panel and runs the length of both panels before it reaches the chains: about 4.9 m routed and 5.6 m with margin, past the 5 m limit of passive USB 2.0, so an active 5 m repeater cable carries it to the webcam's own lead. Two are on hand, a Logitech C270 at 720p and a 1080p module; the C270 is the one fitted, because it is fixed focus and therefore cannot go hunting for focus in the middle of a cycle, which matters more here than the extra pixels. It is refocused by hand: the lens is turned to the working distance over a label and left there, and focus, exposure, gain and white balance are all locked before a batch so nothing drifts between records (`v4l2-ctl -d /dev/video0 --list-ctrls-menus` shows what the model actually exposes). At 720p it resolves the centre hole, the label edge and the groove bands, which is what the cycle needs from it. It does not have to read the label: a record's identity comes from the manifest, not from the photograph (see Web interface), so the label photographs only have to let a person confirm which record was played.

**Display.** A 4.3″ capacitive touch display, 800 × 480, on the Pi's DSI port, which is free because the camera is on CSI. It needs no GPIO pins, no separate supply and no adapter: one 15-pin ribbon carries video, touch and power at about 1.2 W. It sits on the front post of the deck-end panel, 41 cm of ribbon from the Pi, and shows the cycle state, the fault screen and the label photograph of the side being recorded. A small Python renderer draws it with Pillow straight to the framebuffer; there is no browser on the Pi. Mount it so its light does not reach the platter, or it corrupts the strobe speed measurement.

**Deck interface.** The Conrad Components 393905 USB relay card already on hand: four potential-free changeover contacts (24 V / 8 A), USB-powered, switched through the GPIO lines of its Silicon Labs CP210x bridge. On Linux the cp210x kernel driver exposes those lines as a gpiochip (`gpioset`), and the `crelay` tool supports this card directly, so the orchestrator on the Pi switches it with one call. Start/stop uses the DD 3120's remote start/stop jack (6.3 mm), a contact-closure input for the fader-start feature of older mixers: relay channel 1 on a 6.3 mm plug, no soldering in the deck. Because start/stop is on the Pi side rather than in Klipper, the fault response is the orchestrator firing `CUE_UP` through Klipper and opening the relay through USB at the same moment, a few tens of milliseconds apart at most. Fader start normally means the platter runs while the contact is closed and stops when it opens, so `DECK_START` closes the contact and holds it, `DECK_STOP` opens it; confirm on the deck that it is level-driven rather than a toggle, and note that the jack has no effect on speed. The 33 and 45 buttons (there is a 78 too, unused) are momentary switches and get relay channels 2 and 3, soldered with thin wire across the switch legs on the underside of the button board and led out through the case; measure the voltage across each switch first and check whether the deck remembers its speed across power cycles. The quartz-lock button should be left engaged; the deck camera can confirm its LED. The deck's pitch output, if it carries a speed or tacho signal, can feed a counter input on the controller as a second speed reference beside the strobe; what it actually outputs is an open question.

**Sensors.** Mechanical or optical end-stops on X, Y and Z at the home ends; a Hall sensor for the wrist's home position; a slot-type optical sensor reading a home mark on the carousel's tooth ring; an MPRLS pressure sensor on the cup line, on the Pi's I²C bus; optionally a record-present reflective sensor at the pick position, though the wrist camera makes it redundant.

The vacuum sensor is a pressure sensor, not a switch, and it is on the Pi, not the controller. An industrial vacuum switch costs more than the rest of the sensing put together, and a switch only says sealed or not; the MPRLS gives a number, which tells a weak seal from none and goes into the sidecar file. The price is that the seal check cannot live inside Klipper: it is an orchestrator step, and a lost seal is caught one poll interval and one Moonraker round trip after it happens rather than inside the motion queue. That was weighed and accepted — see the decision log — because at every moment a record is carried it is a few centimetres above a surface made to receive it, and a tenth of a second is not what decides whether it lands well. The sensor sits beside the Pi on a tube stub from the valve, because a vacuum line does not care about length and I²C does.

**Cabling.** Three cable chains, not the two the concept drew: one along the X beam carrying everything that rides the gantry; one along the cross beam, because the Y carriage travels 625 mm and a loop will not do it; one along the Z column to the wrist. The vacuum hose runs the same way, on the outside of each bend. Chain lengths and every cable's routed length, with wiggle room, are in `08-assembly-instructions.md`.

## Klipper configuration

The `printer.cfg` declares the four motion axes as a Cartesian kinematics with X, Y, Z, and the wrist as an additional manual stepper, the carousel as a second manual stepper, the cue-lever servo as a `servo` section, the pump, valve and LED as `output_pin` sections (the LED with `pwm: True` and a 20 ms cycle time for the strobe), while the relay card is driven from the orchestrator, not from Klipper: the speed channels pulsed for 150 ms, the start/stop channel held closed while the platter should run.

G-code macros implement the primitives the orchestrator composes: `HOME_ALL`, `PUMP_ON`, `RELEASE` (pump off, valve open for a moment), `CUE_UP`, `CUE_DOWN`, `CAROUSEL_INDEX`, `STROBE_ON`, `LIGHT_ON`, `LIGHT_OFF`, and `EMERGENCY_LIFT`, which is `CUE_UP` followed by a motion halt, bound so it can be fired without waiting for the queue; the orchestrator opens the start/stop relay at the same time.

Klipper's own safety features do the low-level work: TMC stall detection on every axis, soft limits, and a hard limit on Z so the carriage cannot be driven below its lowest working height.

## Orchestrator

A Python service on the Pi that talks to Klipper through Moonraker's API and owns the state machine of the cycle. Each step of the cycle in `02-operating-cycle.md` is one state; each state issues a planned list of waypoints as G-code, waits for completion, checks its post-condition (vacuum seal, camera confirmation, sensor state), and either advances or raises a fault.

The record's size is the orchestrator's too: it reads it from the manifest line and lowers the pick and the return to that size's centre height, the one number in the cycle that depends on what is in the slot; every other target is a datum. A "by hand" line makes it park the gantry and wait for the user at placement, at the flip and at removal, and run the side in between exactly as for a picked record. A batch marked "one side per run" makes it skip the four station steps after the lift and return the record instead; on the second run it compares each label photo with the first run's for the same slot and skips a record that shows the same label, because the user did not turn it.

The grip is the orchestrator's, not Klipper's. `GRIP` is a step: `PUMP_ON` through Klipper, then poll the MPRLS until the pressure falls below the seal threshold set during commissioning, with a timeout that raises a fault. Throughout every carry the orchestrator keeps polling, at 20 Hz or better, and a reading that rises back above the loss threshold sends an emergency stop through Moonraker and holds position. The abort is therefore one poll interval plus one round trip, under a tenth of a second; the pressure at grip and at release is logged with each side.

The motion planner is the same one the concept model uses: retreat, raise, ordered horizontal moves, lower, approach, with per-pose exceptions for the station. Poses are computed from a small set of calibrated datums: the pick slot's centre, the spindle, the ring rest, the arm pivot and the arm's rest, lead-in and run-out angles for the deck in use. Calibration is a guided procedure in the web interface that jogs the axes to each datum with the camera live.

Faults never attempt recovery. The orchestrator fires `EMERGENCY_LIFT` when a side is playing, stops everything else in place, records the state, and notifies the user.

## Vision

OpenCV in Python on the Pi: picamera2 for the deck camera on the CSI port, V4L2 for the webcam on the wrist, with its focus, exposure, gain and white balance locked before every batch.

The wrist camera does four things on each face it sees: finds the centre hole (a dark circle of known size; its offset from the camera axis gives the cup-to-hole offset used when placing on the spindle), finds the label edge, finds the transition from label to lead-out band and from lead-in band to the outer edge (the groove bands differ from the smooth bands in reflectance), and saves a face-on label photograph named by slot and side.

The deck camera tracks the headshell as a dark rectangle in a known region, converts its image position to an arm angle through a calibration, and from the angle derives the stylus radius. It detects the run-out as the radius reaching the value measured on the face-on photo, and a skip as a radius jump larger than the groove pitch between frames. For speed, it tracks either the strobe-lit dots' drift or a single marker on the rim between timestamped frames and reports mean rotation rate and wow; both values go into the recording's sidecar file.

## Recording

`arecord` or a small sounddevice loop captures from the Scarlett at 96 kHz / 24 bit into one WAV file per side, started before the stylus is lowered and stopped after the arm is parked. The WAVs are written to an external USB 3.0 SSD, never to the microSD card: a side is about 860 MB and a full 24-slot magazine about 40 GB, which would both fill the card and wear it out. An SSD rather than a bus-powered hard disk, which draws about 0.9 A on spin-up and puts a vibration source next to the turntable. The phono signal passes through the deck's own phono stage (line output) or an external phono preamp before the Scarlett; the Scarlett has no phono input. A silence detector on the live stream provides the run-out confirmation and the skip detector's audio half.

Each side produces a WAV, both label photos (side A's from the pick, side B's from the re-grip), and a JSON sidecar with slot, manifest line, measured speed and wow, cue and run-out radii, and timestamps. Track cutting, mastering and tagging operate on these later and are out of scope here.

## Web interface

A FastAPI service with a small single-page front end, served from the Pi on the local network. It provides the batch manifest editor (slot, size, speed, the record's identity, flags, or "by hand" for a shaped or off-centre disc that the user lays on the spindle when the machine asks; it refuses a 12" in the slot on the front side of a 7"; a batch-wide "one side per run" switch with the side being recorded), the live views of both cameras, a jog panel and the calibration procedure, a step-through mode that runs the cycle one state at a time for commissioning, the batch status with the current step and the queue, a pause and a resume, and the fault screen with the manual "retry from here". Later the same interface hosts the tag review of the follow-up project.

A record's identity comes from the manifest. The user enters artist, title and label when loading the carousel, ideally as a Discogs release ID that the interface resolves once, at load time; nothing is read from the label photograph. That leaves one gap: nothing checks that a slot physically holds the record its manifest line names, and a slip while loading would make the machine label a recording confidently and wrongly. So the interface shows each side's label photograph beside its manifest text in a per-side review screen, which is the one check between a mis-loaded magazine and a mislabelled archive; see `06-open-questions.md`.

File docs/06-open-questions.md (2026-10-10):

# Open questions

Things the concept could not settle and that the first hardware has to answer. Each one names what to measure and what depends on it.

**The turntable's exact geometry.** Measured on the deck itself: the outline, 44.9 × 35.1 × 8.6 cm from the feet to the case top; the platter, 1.8 cm above the case; the spindle, 17.9 cm from the left edge and 17.4 cm from the rear; the arm pivot, 6.95 cm from the right edge and 9.35 cm from the rear; and the cue lever's top, 4 cm from the right edge, travelling from 14.6 to 12.2 cm from the rear edge as it lifts. The photo had every one of these off by 5 to 20 mm, so what is still taken from it (`images/dd-3120-top.jpg`) should be trusted to a centimetre or two and no better. Still to measure: the arm rest's position, the heights above the case of the arm tube, the lever's top and the finger lift, and the finger lift's shape. The servo's yoke, the end-stop pin and the fork's approach hang on these numbers.

**Whether the re-grip earns its keep.** The flip station is the one place a record is set down and picked up again with nothing centring it, and the decision log keeps it on the condition that it works. Count, over the first batches, how often the re-grip fails to find the hole or to seal, and how often a record on the ring is off its nominal centre by more than the cup's bellows absorb. If it is often, the one-side mode in `02-operating-cycle.md` is the machine's mode and the station comes off; if it is rare, the station stays and the mode remains the fallback.

**Slipmat.** Replace the felt DJ slipmat with a rubber or cork mat before the first batch and check that the vacuum-cup release a few millimetres above it still centres the record on the spindle. The Baumarkt sheet prices a 4 mm cork sheet to cut the mat from, and the CAD now draws a 4 mm mat (`MAT_T` in `cad/params.py`); if a different mat is fitted, set `MAT_T` to it and rerun the collision sweep.

**The remote start/stop jack's behaviour.** Fader start suggests the platter runs while the contact is held and stops when it opens; confirm that it is not a toggle, and whether the front-panel button still works while the remote contact is closed.

**The pitch output.** What signal the DD 3120's pitch output carries: a control voltage, a tacho pulse train, or something else. A pulse train proportional to platter speed would be a second, strobe-independent speed reference for the sidecar file.

**Stylus for the archive pass.** The Ortofon DJ S is spherical and robust, which is right for commissioning and for worn records. Decide after the first batches whether an elliptical stylus is worth a second pass on the records that matter.

**Cue lever force and lift.** The throw is measured: the lever's top moves 24 mm front to back. Still open: how much force it takes, whether the lever stays where it is put in both positions or springs back from one, how high its top stands above the case, and whether it lifts the arm enough for the fork to walk it without the stylus touching a warped record. The MG996R has torque to spare and its yoke carries the lever both ways, so none of the answers changes the mechanism; they set the yoke's height and slot, the horn angles for up and down, and the lift height the deck camera must confirm. The top of a pivoting lever also moves in an arc, so the yoke's slot has to allow for its rise and fall over the stroke.

**Where the end stop really stands.** The pin is drawn on the arm tube's centre line at the angle where the stylus is 53 mm from the spindle, but the tube is drawn 11 mm thick and the pin's sleeve 18 mm, and the real arm is an S, not the straight tube of the model. Drawn as it is, the straight tube would meet the sleeve with the stylus still about 12 cm out. The pin's place has to be found on the deck, with the arm swung by hand to the run-out groove, and put back into `cad/params.py`. It also has to stay in the narrow gap between the platter's rim and the arm base, about 2 cm in the model.

**Finger-lift shape.** Whether the fork's U straddles the actual finger lift cleanly across the whole arc from rest to run-out, or needs a different opening width or a slight yaw. A printed test fork on a hand-held handle answers this in an afternoon before any gantry exists.

**Cup size against 7" labels.** A 40 mm bellows cup on an 88 mm label leaves margin; confirm the seal on printed and glossy labels, on labels with embossed text, and on a shaped picture disc's centre.

**What catches a mis-loaded magazine.** A record's identity comes from the manifest the user fills in at loading, not from the label photograph, so nothing the machine measures checks that slot 7 actually holds the record its manifest line names; a slip while loading produces a recording labelled confidently and wrongly. The planned answer is a per-side review screen that shows the label photograph beside the manifest text. Try it on the first batches: is a glance at a 720p photograph enough to catch a swapped record, how long does reviewing a full magazine take, and does anything cheaper, such as flagging sides whose label photo looks unlike the one stored for that release, earn its keep.

**Gap at the pick slot.** 65 mm between spoke faces at the arm's radius against 48 mm of cup, neck, bracket and arm, leaving 8 mm of approach and 9 mm of margin. Print the wrist's cup end first and check it in a mock-up of three slots; if it is too tight, the fix is 22 slots at 16.4° rather than a wider carousel. The camera is no longer in the gap.

**Carousel indexing accuracy.** Whether a printed GT2 ring in eight segments indexes to within a millimetre at the rim over many revolutions, or whether the per-slot optical mark is needed for every index rather than only for homing.

**Vertical record at travel height.** The planned travel height leaves about 5 cm between the lower edge of a hanging 12" record and the tops of the carousel's combs while it moves along X. Confirm the record's swing when the gantry accelerates; raise the travel height if needed.

**Deck camera view.** Whether the low, oblique view from the end panel sees the headshell over the whole arc and resolves the stylus, or wants a slightly higher mounting; and whether the raking LED at that angle shows the groove bands reliably on dark and on coloured vinyl.

**Skip detection thresholds.** The audio discontinuity and the headshell-radius jump both need thresholds that catch a skip within a second but do not fire on a loud transient or a slightly eccentric pressing. Tune on a deliberately scratched sacrificial record.

**Strobe reading on the clone's platter.** Whether the deck's dot rows are usable under the 50 Hz LED, or whether a printed strobe ring on the rim is the better reference. On a quartz-locked deck the expected result is "no drift"; the test is nudging the pitch fader and watching the number move.

**Phono stage.** Whether the clone's built-in phono stage on its line output is good enough, or an external phono preamp goes between the deck and the Scarlett. Record the same side both ways and compare before deciding.

**Column height.** The raised column top at about 135 cm is fine on a bench but not under a low shelf; if headroom is short, the Z travel can be reduced by lowering the travel height for horizontal carries, at the cost of a slightly longer cycle.

**V-wheel play on X.** With Delrin wheels on V-slot the carriages must be adjusted with their eccentric spacers until there is no rock and no binding over the whole 1.3 m; check that the cup's position at the pick slot repeats to within half a millimetre after a full X traverse, and fall back to a rail on X if it does not.

**Pick without a camera.** The pick relies on the record's centre being within about a millimetre of its nominal position when it has rolled to the apex of the V in its comb. Check this on a printed comb with a 12", a 10" and a 7": drop each into the slot anywhere along its length and measure where it comes to rest. A record that stops short on the 5° slope needs a steeper V, which is one number in `cad/params.py`; if a size still sits off, the wrist camera can take one look from above the slot before the arm descends, at the cost of a few seconds.

**Spindle in the cup.** The spindle tip enters the hollow bellows cup by about 10 mm when a record is released 3 mm above the mat. Confirm the cup's inner depth allows that with the chosen cup; otherwise release from a little higher.

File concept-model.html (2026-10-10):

drag to orbit · wheel to zoom · shift-drag to pan

# AutomaticRecordDigitalizer

Concept model of the automatic record changer for digitising a vinyl collection. Proportions are indicative, not CAD.

## Cycle step

Run the whole cycle

## Rough numbers

Bench

≈ 190 × 100 cm

Frame

125 × 80 × 90 cm · 18 mm ply

Cue lift

deck’s own lever, servo-driven

Linear motion

V-slot X/Y · rail on Z

Column top, raised

≈ 135 cm

Carousel

24 slots · 15° · Ø 86 cm

Gap at the label

≈ 6.5 cm

X travel

≈ 80 cm

Y travel

≈ 45 cm

Z travel

≈ 60 cm

Wrist

−90° … 180°

Show part labels

This revision: the brush module is gone — records are brushed by hand before they go into the carousel, which saves a servo, a bracket and a step. X and Y run on 2040 V-slot with Delrin wheels instead of linear rails; only the Z column keeps a rail. The deck is the Omnitronic DD 3120 with its layout measured from a photo: the cue lever sits at the front-right of the arm base, so its servo lives on the frame’s end panel with a short pusher, and the end-stop pin hangs off a bar from the same bracket. An automatic turntable was considered and rejected: it cannot handle locked grooves, inside-out records or non-standard start and end positions, which is exactly why both cameras stay.

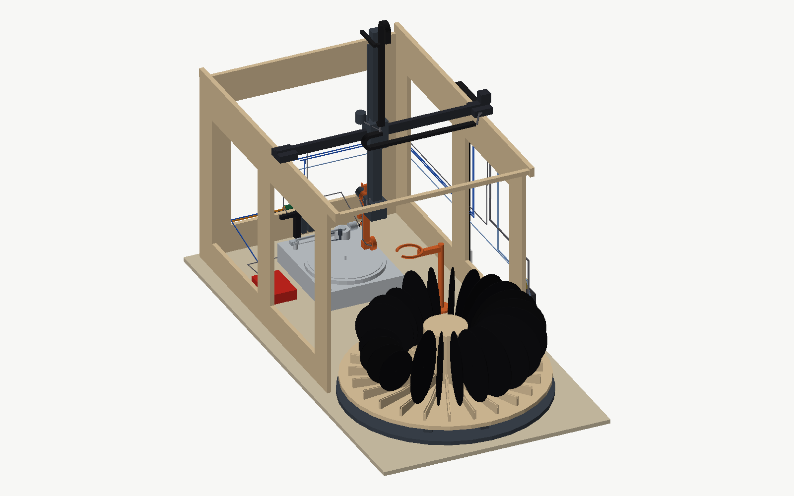
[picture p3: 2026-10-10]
docs/images/render-carousel.png

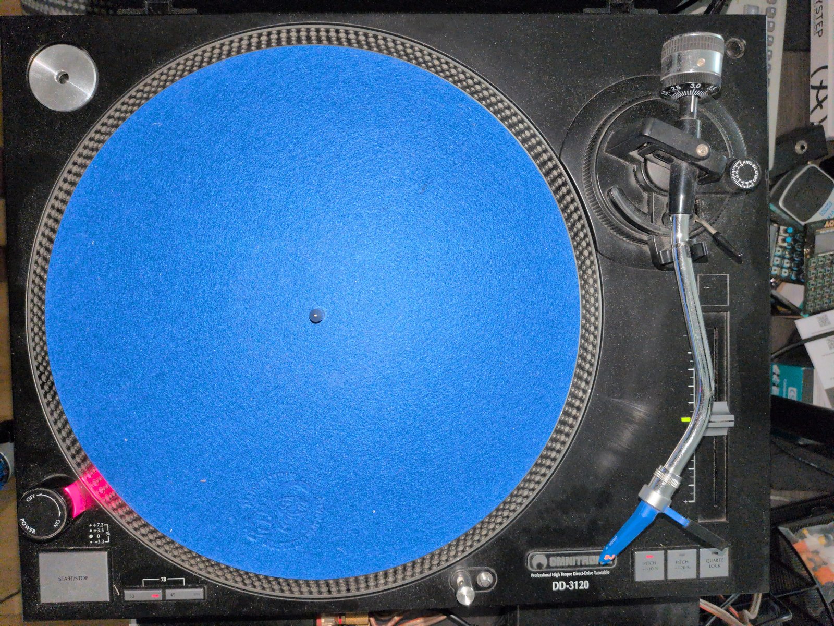
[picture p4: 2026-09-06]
docs/images/dd-3120-top.jpg

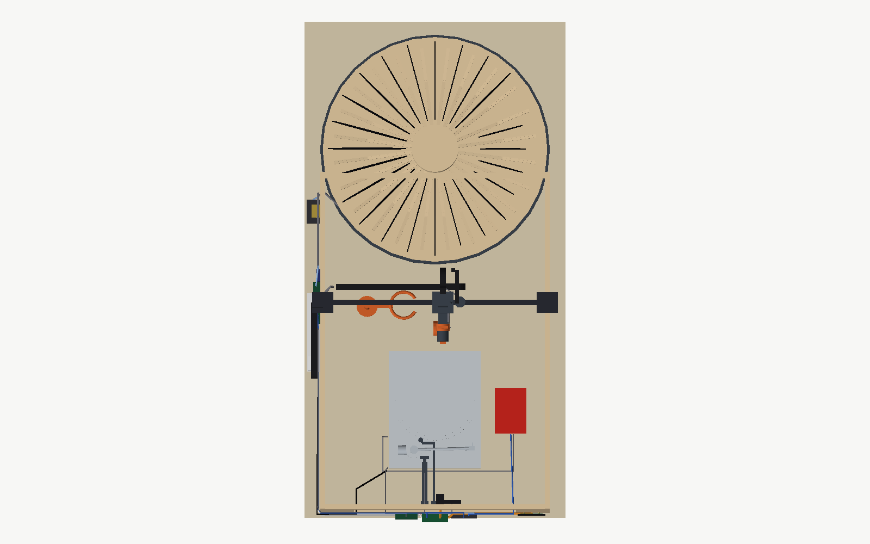
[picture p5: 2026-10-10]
docs/images/render-top.png

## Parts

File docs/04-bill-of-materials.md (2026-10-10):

# Bill of materials

Prices are typical German retail, rounded, and will drift; check before ordering. Every line was priced against live German shop pages on 10 September 2026 and re-verified on 3 October 2026, and the figures below have been corrected where those passes disagreed with the estimate; the itemised result, with product links, three ways of ordering it and a sheet for the Baumarkt, is in [../sourcing/bom-shopping-list.md](../sourcing/bom-shopping-list.md), and what it changed here is in [../sourcing/2026-09-sourcing-and-bom-corrections.md](../sourcing/2026-09-sourcing-and-bom-corrections.md). Everything listed is stocked by German shops, so nothing depends on imports. Suggested sources: shop.bohrers.de or Dold Mechatronik for V-slot extrusion and the linear rail; roboter-bausatz.de for wheels, belts, pulleys, steppers, the lead screw, the servo and fastener assortments; 3DJake for the Octopus, which roboter-bausatz no longer carries; oyostepper.de for the geared steppers; BerryBase and Reichelt for the Raspberry Pi side, cameras, the display, sensors and LED; Conrad for the multi-core extension wire and the USB cables; druckluft-fachhandel.de for the solenoid valve, tubing and push-in fittings; Filamentworld or 3DJake for filament; Hornbach or any Baumarkt for the sheet material, the corner steel, glue and wood screws. Not Motedis: it carries only B-Typ Nut 6 and I-Typ Nut 5 profile and no V-slot at all, so nothing it sells has a wheel-running surface.

## Bought parts

| Group | Part | Qty | ≈ € |
|---|---|---|---|
| Frame | 18 mm OSB 3, two 2500 × 1250 mm sheets, for the three panels; 18 mm MDF, 2440 × 1220 mm, for the two carousel discs; a 25 × 25 × 3 steel angle for the two inside corners, M4 T-nuts and machine screws for the parts that come off again, penny washers for the beam bolts; a further sheet for the bench top only if there is no bench | 2 + 1 | 137 |
| Frame | 2040 V-slot extrusion 1.3 m (X beams) | 2 | 30 |
| Frame | 2040 V-slot 0.94 m (cross beam, spanning the 86 cm frame with the plates outside it), 2020 0.88 m (end tie), brackets, T-nuts, bolts | 1 set | 42 |
| Linear | Delrin V-wheels, four per carriage plate (X ×2, Y ×1), six of them on eccentric spacers | 12 + 6 | 45 |
| Linear | MGN12H rail 0.8 m with carriage (Z column) | 1 | 30 |
| Motion | NEMA17 stepper, plain (X, Y, Z) | 3 | 36 |
| Motion | NEMA17 with 5:1 planetary gearbox (wrist, carousel index) | 2 | 70 |
| Motion | GT2 belt 5 m, 20T pulleys, idlers, tensioners | 1 set | 25 |
| Motion | T8 lead screw 0.8 m, nut, coupler, bearing block | 1 | 20 |
| Servos | MG996R metal-gear servo working the cue lever through a printed yoke on its horn | 1 | 7 |
| Controller | BIGTREETECH Octopus V1.1 (or: donor printer board + Raspberry Pi Pico, see below) | 1 | 65 |
| Controller | TMC2209 driver (5 with the Octopus, 1 with the donor-board option) | 5 | 30 |
| Power | 24 V 150 W supply; 24 → 5 V 3 A buck for the servo; 24 → 12 V 3 A buck for the pump, the valve and the LED bar, which are all 12 V | 1 set | 38 |
| Cameras | Raspberry Pi Camera Module 3 (deck camera; the Pi 4B has one CSI port, so the wrist camera is USB and owned) with a 500 mm ribbon; the Pi sits on the deck-end panel 30 cm away | 1 | 29 |
| Display | Waveshare 4.3″ capacitive touch display, DSI, 800 × 480, on the Pi's free DSI port, with a 500 mm 15-pin ribbon: cycle state, fault screen, the current side's label photo | 1 | 41 |
| Vacuum | 12 V diaphragm vacuum pump | 1 | 11 |
| Vacuum | 12 V 2/2 solenoid valve, G 1/8 NC, FKM — **direct-acting**, not pilot-assisted | 1 | 42 |
| Vacuum | Adafruit MPRLS 0–25 PSI I²C pressure breakout, in place of a vacuum switch | 1 | 31 |
| Vacuum | 40 mm bellows cup, 7 m of 6 × 4 PU tubing (4.5 m to the cup and a 2.1 m stub to the pressure sensor, with wiggle room), push-in fittings, a tee | 1 set | 40 |
| Sensing | End-stops, Hall sensor, slot optical sensor | 1 set | 12 |
| Deck I/O | 6.3 mm mono plug and cable for the remote start/stop jack, thin wire (relay card: Conrad 393905, owned) | 1 | 4 |
| Light | LED bar (12 V, warm white) and logic-level MOSFET | 1 | 8 |
| Carousel | 608ZZ bearing (rollers) | 10 | 6 |
| Carousel | 6005 bearing, 25 mm stub shaft | 1 | 8 |
| Cabling | Cable chain 10 × 20 mm, 3 m for three chains (X 0.7, Y 0.6, Z 0.6 m); 7 m of 4-core and 15 m of 3-core extension wire (LiYY 0.25 mm², two cores of the 3-core for the button taps), 10 m of 20 AWG pair for the 12 V loads; an active 5 m USB 2.0 repeater for the wrist camera and a 3 m USB-A to USB-C cable from the Pi to the controller; connectors, crimps, sleeving | 1 set | 138 |
| Hardware | M3/M5 screws and nuts, heat-set inserts, felt, rubber sleeve stock, one 97 × 3 NBR O-ring for the ring rest | 1 set | 36 |
| Consumables | PETG 2.5 kg, TPU 0.3 kg | | 70 |
| **Total** | | | **≈ 1 051** |

Not included, because they are already on hand: the 3D printer, the turntable (Omnitronic DD 3120), the Focusrite Scarlett, the Conrad 393905 USB relay card, the Raspberry Pi 4B (two of them, the second a cold spare) with its 15 W supply and 32 GB card, the external USB 3.0 SSD the recordings are written to, the self-powered USB 3.0 hub everything else hangs off, and the USB webcams for the wrist (two on hand, a 720p Logitech C270 and a 1080p module). Together those are roughly 185 to 195 € that do not have to be spent. Also not included: an external phono preamp if the deck's own line output is not used (about 40 €).

The table above is the planning estimate, rounded, and it counts the sheet material and the filament. The [sourcing pass](../sourcing/bom-shopping-list.md) priced every line against live shop pages on 10 September and again on 3 October 2026, and costed three ways of actually ordering it, including shipping and excluding filament, sheet material and the other Baumarkt items. The routes include the crimp tool and the heat gun, about 48 €, which this table leaves out with the other tools; parts already ordered on 3 October count as owned. The Baumarkt sheet, priced at Hornbach for pickup, comes on top of whichever route is ordered:

| Route | Parts | Shipping | Delivered |
|---|---|---|---|
| Cheapest per line, 12 suppliers, 12 parcels | 905,67 | 57,30 | **962,97** |
| Consolidated into 8 suppliers | 839,22 | 37,60 | **876,82** |
| With a donor printer, 7 suppliers and the donor | 653,69 | 37,60 | **691,29** |
| Baumarkt, Hornbach pickup, on top of any route | 226,89 | — | **226,89** |

Consolidating is close to free rather than a discount: it costs about 28 € more on parts (the MGN12 rail, the camera, the energy chain) and saves about 30 € on shipping. The gap between the first two routes is almost entirely the servo substitution. Five suppliers is not reachable for the complete list. No German general-purpose shop stocks a NEMA17 with a 5:1 planetary gearbox, so either take 10:1 from Dold, which is fine for the wrist and the carousel since both are slow, or accept another shop; and since October the Octopus and the multi-core wire each pull in one more, 3DJake and Conrad. Six is the realistic floor: 10:1 motors from Dold and the wire from Reichelt.

Where to trim further: the donor printer route above is the real saving. The panels are already the cheap option, OSB 3 instead of birch multiplex, about 136 € less with the steel that makes up for OSB's weak edges (see `05-design-decisions.md`). The two obvious earlier trims are already taken — the computer is an owned Pi 4B, and the wrist camera is an owned USB webcam rather than a second Pi camera.

## Donor printer

A used 3D printer is the cheapest source for most of the motion parts and is worth buying before anything else on the list. What it has to bring: at least four NEMA17 steppers, a 24 V supply, GT2 belts and pulleys, a T8 lead screw, V-slot extrusion with Delrin wheels and carriage plates, end-stops, and ideally a 32-bit board that runs Klipper. Candidates in rough order of usefulness:

| Donor | What it contributes | Notes |
|---|---|---|
| Creality CR-10 / CR-10S (300–500 mm) | 4–5 steppers, 2040/4040 V-slot up to 60 cm, 1–2 lead screws 40 cm, wheels, 24 V PSU, board | The best fit: longest extrusions and lead screws of the cheap decks; the S5 (500 mm) variant most of all |
| Creality Ender 3 Max Neo | 4 steppers, dual Z with two motors, 300 × 300 frame so longer 2040 members than a plain Ender 3, wheels, 350 W supply, 32-bit board | Second only to a CR-10: the bigger frame and the second Z motor and screw are exactly what this machine wants |
| Creality Ender 3 / 3 Pro / V2 | 4 steppers, short 2020/2040 V-slot, 1 lead screw 36 cm, wheels, 24 V PSU, 4.2.x board (Klipper-capable, 4 drivers) | Plentiful and cheap; the long members must still be bought |
| Creality Ender 5 / 5 Plus | 4–5 steppers, 2020/2040 V-slot in a box frame, dual Z screws on the Plus, larger PSU | The Plus gives two lead screws and a 350 W supply |
| Anycubic Kobra / Vyper, Artillery Sidewinder | 4 steppers, 24 V PSU, some extrusion | Less V-slot, boards less Klipper-friendly; take for motors and PSU only |
| Tevo Tornado, Alfawise U20 | CR-10 clones | Same value as a CR-10 if cheap |
| Creality Ender 3 S1 / S1 Pro / S1 Plus | **Avoid.** Steppers and PSU only | Its frame is smooth-faced extrusion, not open V-slot: there is no groove for a wheel to run in, so neither the profile nor the wheels are reusable here |

Whatever the donor, the long V-slot beams (2 × 1.3 m) and the 80 cm Z rail and lead screw are bought new; the donor covers motors, wheels, belts, pulleys, end-stops, PSU and fasteners, roughly 150 to 200 € of the list above, for a 50 to 100 € machine. Its board can run the four gantry axes under Klipper with a Raspberry Pi Pico (about 4 €) plus one TMC2209 stick (about 6 €) as a second MCU for the carousel stepper and the remaining I/O, which replaces the Octopus and its five drivers, about 92 € of the list for about 10 €; or it is kept as a spare and the Octopus bought as planned.

The donor is bought: a Creality Ender 3 V2, on 6 October 2026 for 55 € including delivery, 20 € under the estimate the donor route was priced with. It arrives the week of 12 October; until it has been run once, stripped and counted, the lines it is meant to cover stay open.

Two things to check on the donor before counting on its board. Only the 32-bit Creality 4.2.2 and 4.2.7 boards run Klipper; an 8-bit 1.1.4 board does not, and then the Octopus goes back on the list. And the TMC drivers on the 4.2.x boards are soldered down, not socketed sticks, so they cannot be harvested — whatever else the donor gives, the drivers for any axis it does not run itself are bought new.

## Printed parts

Roughly 30 distinct parts, 50 to 70 hours of printing. PETG unless marked TPU.

| Assembly | Parts |
|---|---|
| Gantry | 2 V-wheel carriage plates for the X beams (or the donor's), cross-beam end brackets, Y wheel plate, Z guide block, Z carriage with outrigger, lead-screw nut holder, column end caps |
| Wrist | hub with bearing seats, arm, cup bracket, hose clip, wrist camera mount, finger-lift fork with TPU lining, Hall sensor mount |
| Carousel | centre hub, 24 slot combs with V floors, 8 GT2 tooth-ring segments, 10 roller brackets, stepper mount with pulley, home-mark flag and sensor mount |
| Station | ring rest with a rubber O-ring in its top groove, post foot; controller plate and Pi plate for the panel outsides, pump mount on rubber feet |
| Deck interface | cue-servo post and beam, horn yoke for the lever, end-stop bar and pin base with TPU sleeve |
| Cameras and light | deck camera bracket, LED bar housing, cable-chain end brackets |

Something soft goes on every surface that touches a record: TPU for the cup lip if it is not bought, the fork lining and the end-stop sleeve; a bought rubber O-ring on the ring rest.

## Wood and other cut parts

From the sheet material: two side panels 121 × 83 cm with windows, one end panel 84 × 83 cm with a window (it sits between the side panels, whose inner faces are 84.2 cm apart), the bench top 190 × 100 cm (or an existing bench), the carousel disc Ø 86 cm, and the carousel base plate Ø 88 cm. That is two 2500 × 1250 OSB sheets for the panels, both side panels on one and the end panel on the other, and one 2440 × 1220 MDF sheet for the discs, which fit side by side with 700 mm to spare, plus a further sheet for the bench top. The cut list with the window sizes and the nesting is in `08-assembly-instructions.md`. None of the cuts needs to be better than a few millimetres; the precise surfaces are all bought (rails on extrusion) or printed (carousel hub and combs).

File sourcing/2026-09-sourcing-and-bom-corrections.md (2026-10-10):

# Sourcing pass, September 2026 — corrections to the bill of materials

Every line of `docs/04-bill-of-materials.md` priced against live German shop pages on 10 September 2026, incl. 19 % VAT, delivered to Germany. Amazon.de and Conrad.de block automated fetching, so they were excluded rather than guessed at.

The itemised result, with product links, three ways of ordering it and a sheet for the local Baumarkt, is in [bom-shopping-list.md](bom-shopping-list.md). Every priced line was fetched again on 3 October 2026, and the panel material was decided on 4 October; what those changed is at the end of this file.

The headline: the BOM's estimate of ≈ 865 € holds up in aggregate, but only because it is the sum of two large errors in opposite directions plus a lot of accurate lines. The corrections below have been absorbed into the repo docs.

## Corrections

### Micro linear servo: 12 € is wrong by 10×

*Material · affects `docs/04-bill-of-materials.md`*

No sub-30 € linear servo is in stock at any German or EU shop. Verified: Actuonix PQ12-S 123,49 €, MightyZAP 6N 90,95 €. An MG996R metal-gear servo at 6,65 € driving the existing printed pusher rod does what the cue lever needs — a bracket change, not a design change.

### Vacuum switch: the 12 € sensing set cannot cover it

*Material · affects `docs/04-bill-of-materials.md`*

Industrial vacuum switches start at 95,30 € in Germany. An Adafruit MPRLS absolute-pressure breakout at 30,90 € plus a software threshold replaces it — but see the open question below, because it moves where the check lives.

### The solenoid valve must be direct-acting

*Important · affects `docs/04-bill-of-materials.md`*

Pilot-assisted valves (the common 2V025 type) do not open at zero differential pressure, i.e. under vacuum. Verified suitable: 2/2-way G 1/8″ NC, FKM, 12 V, direktgesteuert, 0–16 bar — 42,44 €.

### Motedis cannot supply the extrusion

*Important · affects `docs/04-bill-of-materials.md`*

It is named first under suggested sources, but Motedis carries no V-slot profile at all — only B-Typ Nut 6 and I-Typ Nut 5, which have no wheel-running surface. Use shop.bohrers.de at 12,90 €/m, or Dold at 14,00 €/m plus a 0,50 € cutting fee.

### The computer becomes a Raspberry Pi 4B rev 1.1, 2 GB

*Change of plan · affects `docs/03-electronics-and-software.md`*

Already owned, two of them. One CSI port instead of two, so the wrist camera takes the USB branch the doc already sanctions and the CSI-HDMI extender leaves the BOM entirely. WAVs go to an external USB 3.0 SSD, never the card — about 860 MB per side, 40 GB per magazine. Everything USB on a powered hub with udev-pinned device names. rev 1.1 refuses e-marked USB-C cables.

### Where does the GRIP post-condition live now?

*Material · affects `docs/06-open-questions.md`*

docs/03 puts the vacuum switch on a controller end-stop input and has GRIP wait on it inside Klipper. An MPRLS is an I²C device on the Pi, so that check moves to the orchestrator and a failed grip no longer aborts inside the motion queue. Either keep a cheap digital switch purely as the Klipper interlock, or accept the latency and document it. Needs deciding before anything is wired.

### Are 720p label photographs enough for Discogs matching?

*Change of plan · affects `docs/06-open-questions.md` · retired on 3 October 2026*

The wrist camera now tops out at 720p. If the tagging stage needs better, the answer is a static high-resolution label camera at the station — not a heavier camera on the moving wrist. Retired once record identity was decided to come from the manifest: see the re-verification below.

### Donor table: three corrections

*Change of plan · affects `docs/04-bill-of-materials.md`*

Add the Ender 3 Max Neo near the top — 300×300 frame, dual Z with two motors, 32-bit board, 350 W supply. Add the Ender 3 S1 family as avoid: its frame is smooth-faced extrusion, not open V-slot, so frame and wheels are useless here. And note that TMC drivers on Creality 4.2.x boards are soldered down, so they cannot be harvested.

## Raspberry Pi 4B: the gotchas worth reading before wiring

- rev 1.1 boards refuse power from e-marked USB-C cables — use the official supply or a plain cable. Verify the board with `cat /proc/cpuinfo`, which should show `a03111`.
- rev 1.1 puts the SD-card voltage regulator on the underside next to the slot, where it is easy to knock off. Set the card up once and leave it alone.
- Inside a closed electronics box under sustained vision load, a Pi 4 wants a heatsink and a fan.
- The Pi 4 budgets roughly 1.2 A across all four USB ports. Put the Scarlett, the SSD, the webcam and the relay card on a self-powered hub, and pin every device with a udev rule so `/dev/video*` and the ALSA card index do not shuffle across reboots.
- Do not run the Pi from the servo's 5 V buck converter: an MG996R stalls at about 2.5 A and will brown the Pi out.
- CPU is roughly 2 to 2.5× less than a Pi 5. The workload absorbs it because the only sustained vision load is the deck camera tracking the headshell in a known ROI — keep those frames at about 640 × 480, 10–15 fps, and process the 12 MP label shots one at a time.

## Errata from the consistency check, 14 September 2026

Checking the bill of materials against `cad/params.py` and the planner's actual travel changed these lines after the pricing pass. The shopping list above still shows the lengths as priced; order these instead.

- **2040 cross beam: 940 mm, not 800.** The frame is 860 mm wide over the panels and the X carriage plates sit outside it. The 800 mm cut is the concept's 80 cm frame, which the CAD widened to 86 and the cut list never followed. Same profile, same shop; about 2 € more.
- **2020 end tie: 880 mm, not 800**, over the two X beams. Still cut from the 1 m length.
- **End panel: 842 × 830, not 800 × 830.** It sits between the side panels' inner faces.
- **Plywood: two 1500 × 3000 sheets, not one** — panels on one, both carousel discs on the other — and a third if the bench top is cut rather than existing.
- **V-wheels: 12, not 9.** Four per carriage plate, three plates, six eccentric spacers as priced.
- **A 24 → 12 V buck, about 3 €**, was missing altogether: the pump, the valve and the LED strip are 12 V parts and the list has only a 24 V supply and a 5 V buck.
- **Cable chain: three chains, 700 + 600 + 600 mm.** The Y carriage travels 625 mm along the cross beam, which the concept forgot. The 3 m priced covers it with a metre spare.
- **PU tube: 7 m, not 5.** With the electronics on the frame the run from the pump to the cup is 4.5 m with wiggle room, and a 2.1 m stub carries the vacuum to the pressure sensor beside the Pi.
- **Not on the list at all**: about 6 m of 4-core, 12 m of 3-core and 4 m of 2-core extension wire, because the motors come with about 1 m of lead and the sensors with none; a 2 m USB 2.0 A-to-A extension for the wrist camera; and a 3 m USB-C cable from the Pi to the Octopus, now that the two sit at opposite ends of the frame. The 0.5 m camera ribbon is right: the Pi mounts on the deck-end panel, 30 cm from the camera. The routed lengths are tabulated in `docs/08-assembly-instructions.md`.

## Decided since, 14 September 2026

- The `GRIP` post-condition lives in the orchestrator, on the MPRLS alone; no switch, no Klipper interlock. `docs/05-design-decisions.md`.
- The electronics sit on the frame, not in a box; the Pi is on the deck-end panel and the 0.5 m camera ribbon is right.
- 720p label photographs: still to be tried on a batch. The 1080p webcam already on hand is the first fallback.

## Re-verification, 3 October 2026

Every priced line of the shopping list was fetched again, and the list was checked line by line against `docs/04-bill-of-materials.md` and the cable table in `docs/08-assembly-instructions.md`. Against the 10 September figures the three routes are up by 70 to 80 € each. About 48 € of that is two tools added on 20 September, the SN-01BM crimper and a heat gun. The rest is mostly parts that were missing, not parts that got dearer.

### Two parts discontinued, five lines missing

*Material · affects `sourcing/bom-shopping-list.md`*

roboter-bausatz has dropped the Octopus V1.1, now from 3DJake at 65,99 € with free shipping and only two in stock, and the 17HS4417P1 stepper; the 17HS4417P1-X4 is the same motor with a different cable, at 11,95 € instead of 15,54 €. Against `docs/04` the list lacked the second buck converter, the pneumatic tee, both USB cables and the multi-core extension wire, and still carried the cross beam at 800 mm (940), the end tie at 800 (880), nine wheels (twelve) and 5 m of tube (7) — the errata of 14 September below, which the list itself had never absorbed. Eleven roboter-bausatz prices had moved and three of the September prices were the wrong quantity tier. druckluft-fachhandel adds 9,90 € of Anbruchkosten to any tube order under 50 m, now its own row. The multi-core wire forces Conrad into the order: it is the only shop with verified multi-core meterware, though Reichelt very likely has the same LiYY and blocked the re-check.

### Wood: the disc sheet halves, the panel sheet is a choice

*Material · affects `docs/04-bill-of-materials.md`, `docs/08-assembly-instructions.md`*

The bill of materials' 120 € for two sheets was wrong by a factor of about 3.5. The two carousel discs fit an MDF E1 sheet 2440 × 1220 × 18 at 49,95 €, in stock — MDF is right for the discs, which need flatness rather than stiffness. The three frame panels fit one sheet only if it is 3000 × 1500, which at Hornbach means birch multiplex at 222,80 €, a store order of four to five weeks. Every cheaper material needs two 2500 × 1250 or 2440 × 1220 sheets: OSB 3 at 62,18 € (rough, chips at the cut-outs, holds the bracket screws less well), maritime-pine plywood at 188,00 €, birch-faced eucalyptus at 218,00 € (in stock, no wait). Wood for the whole machine: 272,75 € in birch and MDF, 112,13 € at the cheapest.

### New line: a 4.3″ DSI status display

*Change of plan · affects `docs/03-electronics-and-software.md`, `docs/04-bill-of-materials.md`*

A Waveshare 4.3″ capacitive touch display, 800 × 480, shows the cycle state, the fault screen and the current side's label photograph. It uses the Pi 4B's free DSI port — the camera is on CSI — so it needs no GPIO, no separate supply and no adapter: one 15-pin ribbon carries video, touch and power at 1.2 W. 37,90 € plus a 2,90 € 500 mm ribbon. It sits on the deck-end panel's front post, a 41 cm ribbon run from the Pi, is drawn by a small Python renderer straight to the framebuffer rather than by a browser, and must be mounted so its light misses the platter, or it corrupts the strobe speed measurement.

### Decided: record identity comes from the manifest

*Decision · affects `docs/03-electronics-and-software.md`*

Artist, title and label are entered by the user when loading the carousel, ideally as a Discogs release ID resolved once at load time, and never read from the label photograph. The manifest grows to carry them. This retires the 720p question above: matching never depends on the label photographs, so they only need to let a person confirm a record later.

### What catches a mis-loaded magazine?

*Open question · affects `docs/06-open-questions.md`*

With identity coming from the manifest, nothing checks that slot 7 physically holds the record the manifest claims, and the machine will label the recording confidently and wrongly. The label photograph is captured anyway, so show it beside the manifest text in a per-side review screen. It is the only thing between a slip while loading and a mislabelled archive.

### Cable check against the CAD routes

*Material · affects `docs/04-bill-of-materials.md`, `docs/08-assembly-instructions.md`*

Everything Klipper-side reaches as tabulated. Three things did not. The wrist webcam is read by the Pi, so its cable starts at the hub in the Pi group and runs the length of both panels before the chains: about 4.9 m routed, 5.6 m with margin, past the 5 m passive USB 2.0 limit, so the 2 m passive extension becomes an active 5 m repeater. The Oyostepper geared motors come with 500 mm bare leads, not the 1 m assumed, so the 4-core is 7 m rather than 6. And the 3 m of thin 2-core for the 33/45 button taps had no line anywhere, so the 3-core is 15 m rather than 12 and two of its cores serve. The Pi-to-Octopus cable is USB-A on the Pi to USB-C on the board. The Z chain carries the hose, the USB cable, the 4-core and the 3-core side by side at about 19 of its 20 mm width: full, and accepted, so nothing more goes into it later.

### Order status

*Status · affects `sourcing/bom-shopping-list.md`*

The BerryBase part of the list was ordered on 3 October: the Camera Module 3, the display, the pump, the MPRLS, the KY-003 Hall sensor, the JST connector kit and an Armor aluminium shell with twin fans for the Pi. Those rows are now at 0,00 € like the other owned hardware. The heat gun and both USB cables moved to Conrad, which is in the order for the wire anyway and passes its free-shipping line with them, and the two 50 cm ribbons to welectron.

## Decided 4 October 2026: OSB panels, steel where OSB is weak, MDF discs

*Decision · affects `docs/01-design-specification.md`, `docs/04-bill-of-materials.md`, `docs/05-design-decisions.md`, `docs/08-assembly-instructions.md`*

The three frame panels are OSB 3, 18 mm, from two 2500 × 1250 sheets at 31,09 € each, in place of the 222,80 € birch sheet with its four-to-five-week store order. Both side panels come from one sheet and the end panel from the other, cut to rectangles at the Markt so nothing larger than 1210 × 830 has to go in the car; the second sheet leaves about 1.1 m² of offcut. The maritime-pine and birch-faced eucalyptus alternatives priced on 3 October are out. The discs stay MDF E1, cut at the Markt into an 880 and an 860 square.

OSB is stiff enough for a glued box but weak in three places, and each gets steel or a fastener instead:

- Screws into its edge hold poorly, so the two corners where the side panels meet the end panel get a 25 × 25 × 3 steel angle the full 830 mm height, screwed into both faces with 3.5 × 16 screws every 120 mm. The glue and the edge screws stay as well.
- Wood screws strip it when taken out and put back, so every part that comes off again sits on M4 T-nuts pressed in from the far face, with M4 × 30 machine screws: the controller plate, the Pi plate, the cue-servo and camera brackets, the display mount and the pump mount, about 18 positions. Printed parts that stay put still go on 3.5 mm wood screws into the face, which hold fine.
- A bolt head pulls into its strands, so the M5 beam bolts get 15 mm penny washers on the panels' outer faces.

The window corners get a 20 to 26 mm hole drilled first, so the jigsaw never has to turn in OSB; round corners stop both chipping and cracks. The metal and fasteners add 24,70 €. Wood and metal together come to 136,83 €, where birch and MDF alone were 272,75 €, and the Hornbach sheet drops from 362,81 € to 226,89 €, all shelf stock with no lead time.

The sheet bought for the carousel base plate is 18 mm, where `cad/params.py` had drawn the plate 15 mm thick (`CAR_BASE_T`), a figure that predated the material decision. The model now draws it at 18 mm, and the disc sits on its rollers 3 mm higher with it, so every pick height follows; exports, renders and the collision sweep were regenerated with the change.

## Donor bought, 6 October 2026

*Status · affects `sourcing/bom-shopping-list.md`, `docs/04-bill-of-materials.md`, `docs/07-status-and-next-steps.md`*

The donor for the third route is a Creality Ender 3 V2, bought on eBay for 55 € including delivery, against the 75 € the route had been priced with; it arrives the week of 12 October. The donor route drops to 653,69 € of parts and 691,29 € delivered. What it actually contains still decides several of that route's lines: run it once before stripping it, note the board revision and the MCU marking (an STM32F103, or a GD32 clone that needs different Klipper build options), and count the wheels and eccentrics against the 12 and 6 the build needs before ordering the rest.

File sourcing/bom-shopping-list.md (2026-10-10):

# Shopping list, priced 10 September 2026, re-verified 3 October 2026

Every line of `docs/04-bill-of-materials.md` against live German shop pages, incl. 19 % VAT, delivered to Germany, excluding shipping in the unit prices and adding it per supplier at the end of each route. Every priced line was fetched again on 3 October 2026; each note carries the date it was last confirmed. The Hornbach sheet was updated on 4 October 2026, when the panel material was decided.

Three ways to order the same machine, and a fourth sheet for what a local Baumarkt supplies, which comes on top of whichever route is ordered. Rows at 0,00 € are hardware already owned, already ordered, or supplied by a donor printer; they are listed so the build stays complete, and they carry no cost so the totals stay honest. Filament is excluded throughout. The three routes include two tools, the SN-01BM crimper and a heat gun, which the bill of materials leaves out by its own convention.

Prices drift — re-check before ordering. Lines marked ESTIMATE could not be fetched. Reichelt blocked automated access on the re-check, so its lines still carry 10 September prices.

| Route | Parts | Shipping | Delivered |
|---|---|---|---|
| [Cheapest per item](#cheapest-per-item) | 905,67 | 57,30 | **962,97** |
| [Fewest suppliers](#fewest-suppliers) | 839,22 | 37,60 | **876,82** |
| [Donor printer route](#donor-printer-route) | 653,69 | 37,60 | **691,29** |
| [Hornbach (local)](#hornbach-local) | 226,89 | 0,00 | **226,89** |

The notes under each route call the first three sheet 1, sheet 2 and sheet 3, in the order of the table above.

The corrections the pricing passes produced, and which repo documents absorbed them, are in [2026-09-sourcing-and-bom-corrections.md](2026-09-sourcing-and-bom-corrections.md).

## Cheapest per item

Sourced from German shops, delivered to Germany. Prices incl. 19% VAT, verified 10 September 2026, re-verified 3 October 2026. Source BOM: github.com/drehtuer/AutomaticRecordDigitalizer/blob/main/docs/04-bill-of-materials.md

| Group | Part | Qty | Unit € | Line € | Supplier | Note |
|---|---|---|---|---|---|---|
| Frame | [Aluprofil 2040 V-Slot Nut 6 black, cut 1300 mm (12,90 €/m)](https://shop.bohrers.de/V-Slot-2040-Zuschnitt.html) | 2 | 16,77 | 33,54 | shop.bohrers.de | verified 03.10.2026; X beams. 1300 mm needs the extended-length option in the configurator and the cut fee is charged on top - the cart shows the final figure |
| Frame | [Aluprofil 2040 V-Slot Nut 6 black, cut 940 mm (cross beam)](https://shop.bohrers.de/V-Slot-2040-Zuschnitt.html) | 1 | 12,13 | 12,13 | shop.bohrers.de | verified 03.10.2026; docs/04 wants 940 mm, the list had 800 - corrected |
| Frame | [V-Slot 2020 profile, black, 1 m (end tie, cut to 880 mm)](https://www.roboter-bausatz.de/p/v-slot-aluminiumprofil-2020-1-meter-schwarz) | 1 | 5,95 | 5,95 | roboter-bausatz.de | verified 03.10.2026; docs/04 wants 880 mm, the list had 800 - a 1 m length still covers it |
| Frame | [2020 Winkel Nut 6 mit Nutfuehrung, silver (brackets)](https://www.roboter-bausatz.de/p/2020-winkel-fuer-aluminiumprofile-nut-6-mit-nutfuehrung-silber) | 20 | 0,55 | 11,00 | roboter-bausatz.de | verified 10.09.2026; 0,55 € from 20 pcs |
| Frame | [Nutenstein M5 Nut 6, slide-in (T-nuts)](https://www.roboter-bausatz.de/p/nutenstein-m5-nut-6-einschiebbar) | 50 | 0,25 | 12,50 | roboter-bausatz.de | verified 10.09.2026; 0,25 € from 100 pcs -> order 100 |
| Frame | [20x M5 Hammerkopfschraube Nut 6, 10 mm (T-head bolts, 5 packs = 100)](https://www.roboter-bausatz.de/p/20x-m5-hammerkopfschraube-nut-6-10mm) | 5 | 2,07 | 10,35 | roboter-bausatz.de | verified 03.10.2026; 2,07 € per pack in the 5-pack tier |
| Linear | [Solid Delrin V Wheel Kit (wheel + 2x 625 bearings + shim + nut + screw)](https://www.roboter-bausatz.de/p/solid-delrin-v-wheel-kit-fuer-openbuilds-v-slot-rail) | 12 | 4,15 | 49,80 | roboter-bausatz.de | verified 03.10.2026; docs/04 counts 12 wheels, the list had 9 - corrected. Dual V-Wheel Kit at 2,65 €/pc saves 18,00 € |
| Linear | [Exzentrischer Abstandshalter 5 mm (eccentric spacers)](https://www.roboter-bausatz.de/p/exzentrischer-abstandshalter-fuer-v-slot-rollen-5mm-bohrung) | 6 | 1,25 | 7,50 | roboter-bausatz.de | verified 03.10.2026; 5+ tier; never included in wheel kits |
| Linear | [MGN12 linear rail, cut 800 mm (35,00 €/m) - Z column](https://shop.bohrers.de/linearfuehrung-fuer-mgn12.html) | 1 | 28,00 | 28,00 | shop.bohrers.de | verified 10.09.2026; ships oiled, clean and re-lube |
| Linear | [MGN12H carriage / Lagerbock](https://shop.bohrers.de/mgn12h-lagerbock.html) | 1 | 11,00 | 11,00 | shop.bohrers.de | verified 10.09.2026 |
| Motion | [NEMA17 stepper 17HS4417P1-X4, 1.7 A, 40 Ncm, 40 mm, 1 m cable (X, Y, Z)](https://www.roboter-bausatz.de/p/nema-17-schrittmotor-17hs4417p1-x4-2.6v-1.7a-40mm) | 3 | 11,95 | 35,85 | roboter-bausatz.de | verified 03.10.2026; RBS12803, in stock 1-3 days. The plain 17HS4417P1 the list had is DISCONTINUED (page says Nicht mehr verfuegbar even though the category tile still shows it). Same motor, only the cable variant differs - and 3,59 € cheaper |
| Motion | [NEMA17 planetary gearbox 5:1, 44 Ncm, 1.68 A (wrist, carousel)](https://www.oyostepper.de/goods-298-NEMA-17-Planetengetriebe-Schrittmotor-5-1-Nema17-28V-44Ncm-035-Grad-168A-Getriebe-Schrittmotor.html) | 2 | 32,38 | 64,76 | oyostepper.de | verified 03.10.2026; on promotion at 30,76 € on 03.10. 500 mm bare leads, no connector - crimp XH plugs with the SN-01BM. No German shop consolidates this |
| Motion | [GT2 open timing belt 6 mm, 10 m](https://www.roboter-bausatz.de/p/10-meter-gt2-zahnriemen-offen-6mm) | 1 | 9,99 | 9,99 | roboter-bausatz.de | verified 10.09.2026; 10 m cheaper than the 5 m rolls |
| Motion | [GT2 pulley 20T, bore 5 mm, for 6 mm belt](https://www.roboter-bausatz.de/p/gt2-riemenscheibe-20-zaehne-5mm-bohrung-fuer-6mm-riemen) | 4 | 1,04 | 4,16 | roboter-bausatz.de | verified 03.10.2026; 1,04 € for 1-4 pcs - the 0,77 € the list had is the 10+ tier |
| Motion | [GT2 idler 20T, bore 5 mm, dual ball bearing](https://www.roboter-bausatz.de/p/gt2-riemenscheibe-20-zaehne-5mm-bohrung-mit-dual-kugellager) | 4 | 1,55 | 6,20 | roboter-bausatz.de | verified 03.10.2026; regular price; on sale at 1,24 € on 03.10 |
| Motion | [Smooth Idler Spannrolle Kit (belt tensioner)](https://www.roboter-bausatz.de/p/smooth-idler-spannrolle-kit) | 2 | 5,15 | 10,30 | roboter-bausatz.de | verified 10.09.2026 |
| Motion | [Trapezgewindespindel T8 800x8 mm with brass nut](https://www.roboter-bausatz.de/p/trapezgewindespindel-800x8mm-mit-messingmutter) | 1 | 12,39 | 12,39 | roboter-bausatz.de | verified 03.10.2026 |
| Motion | [Shaft coupling 5 mm -> 8 mm (rigid)](https://www.roboter-bausatz.de/p/wellenkupplung-5mm-auf-8mm) | 1 | 1,99 | 1,99 | roboter-bausatz.de | verified 03.10.2026; flexible jaw coupler out of stock at RB |
| Motion | [KFL08 flange bearing block, 2 pcs](https://www.roboter-bausatz.de/p/kfl08-stehlager-mit-flansch-2-stueck) | 1 | 3,71 | 3,71 | roboter-bausatz.de | verified 03.10.2026 |
| Servos | [Actuonix PQ12-S micro linear actuator, 20 mm stroke, limit switches](https://www.nodna.de/Actuonix-PQ12-S-Micro-Linear-Actuator-Linear-Servo-Actuator-with-Limit-Switches_1) | 1 | 123,49 | 123,49 | nodna.de | verified 10.09.2026; BOM budgets 12 € - see note 3, MG996R servo + printed linkage = 6,55 € |
| Controller | [BIGTREETECH Octopus V1.1 mainboard](https://www.3djake.de/bigtreetech/octopus) | 1 | 65,99 | 65,99 | 3djake.de | verified 03.10.2026; roboter-bausatz has DISCONTINUED it (Nicht mehr verfuegbar). 3DJake: 2 in stock, restock underway, ships free - order this one promptly. Fallback at 3DJake: Octopus Pro F446 79,99 € (4 in stock) |
| Controller | [5x BIGTREETECH TMC2209 V1.3 UART incl. heatsinks](https://www.roboter-bausatz.de/p/5x-bigtreetech-tmc2209-v1.3-schrittmotortreiber-uart) | 1 | 26,59 | 26,59 | roboter-bausatz.de | verified 03.10.2026; 5-pack saves 3,66 € vs singles at 6,05 € |
| Power | [MEAN WELL LRS-150-24, 24 V / 6.5 A / 150 W](https://www.reichelt.de/de/de/shop/produkt/schaltnetzteile_156_w_24_v_6_5_a-202987) | 1 | 18,50 | 18,50 | reichelt.de | verified 10.09.2026; Pollin has it at 17,40 € - not worth a 13th order |
| Power | [Mini step-down module 3 A, 4.5-28 V in, adjustable (2 pcs: one set to 5 V for servo + sensors, one to 12 V for pump, valve, LED)](https://www.roboter-bausatz.de/p/mini-spannungswandler-step-down-modul-3a) | 2 | 1,25 | 2,50 | roboter-bausatz.de | verified 03.10.2026; the 12 V module was missing from the list - docs/04 has two bucks |
| Computer | Raspberry Pi 4 Model B rev 1.1, 2 GB RAM (2 on hand; 2nd = cold spare) | — | — | 0,00 | ALREADY OWNED | ALREADY OWNED - saves 120,60 € and dodges the Pi 5 backorder. REV 1.1 WARNING: refuses power from e-marked USB-C cables; use the official PSU or a plain cable. Verify: cat /proc/cpuinfo -> a03111 |
| Cooling | [Armor Gehaeuse mit Luefter fuer Raspberry Pi 4 (full-board aluminium heatsink shell + twin 5 V fans)](https://www.berrybase.de/armor-gehaeuse-mit-luefter-fuer-raspberry-pi-4-schwarz) | — | — | 0,00 | ALREADY OWNED | ORDERED at BerryBase on 03.10.2026 (owner) - now on hand. verified 20.09.2026; 90 in stock. The Pi is mounted in the open on a panel plate under sustained OpenCV load: the shell cools CPU, RAM and USB chip passively, the fans add headroom. Fans plug on 5 V + GND header pins, no GPIO used, ~0.5-1 W. CSI and DSI slots stay open. Passive-only shell 7,50 €; stick-on 4-piece set 1,90 € + 30 mm fan 2,30 € is the floor but needs a printed fan bracket |
| Computer | Official Raspberry Pi 15W USB-C PSU (Pi 4 takes 15 W, not 27 W) | — | — | 0,00 | ALREADY OWNED | ALREADY OWNED presumed - check you still have the Pi 4 supplies. Do NOT run the Pi off the servo 5 V buck: an MG996R stalls at ~2.5 A and will brown out the Pi |
| Computer | microSD card 32 GB (OS, Klipper, orchestrator, logs only) | — | — | 0,00 | ALREADY OWNED | ALREADY OWNED - 32 GB is ample; nothing the machine records is written to it |
| Computer | External USB 3.0 SSD for the WAV files, >=500 GB | — | — | 0,00 | ALREADY OWNED | ALREADY OWNED / to hand. ~860 MB per side, ~40 GB per full 24-slot magazine. SSD not HDD: a bus-powered 2.5in HDD pulls ~0.9 A on spin-up and is a vibration source next to the turntable |
| Computer | Self-powered USB 3.0 hub (Scarlett + SSD + webcam + relay card) | — | — | 0,00 | ALREADY OWNED | ALREADY OWNED - the Pi 4 budgets only ~1.2 A across all four ports. Route everything through the powered hub, and pin device names with udev rules so /dev/video* and the ALSA index do not shuffle on reboot |
| Cameras | [Raspberry Pi Camera Module 3, 12 MP (deck camera)](https://www.welectron.com/Official-Raspberry-Pi-Camera-Module-3) | — | — | 0,00 | ALREADY OWNED | ORDERED at BerryBase on 03.10.2026 (owner) - now on hand. verified 10.09.2026; only one needed now - the Pi 4B has a single CSI port |
| Cameras | [Groundmicro FPC cable 1.00 mm pitch 15-pin, 50 cm, for Raspberry Pi CSI/DSI (deck camera -> Pi 4B CSI; spare)](https://www.welectron.com/Groundmicro-FPC-Cable-100mm-Pitch-15-Pin-for-Raspberry-Pi-CSI-DSI) | 1 | 2,90 | 2,90 | welectron.com | verified 03.10.2026; pick 50 cm in the length selector (5-100 cm offered), 100+ in stock. Re-sourced away from BerryBase. OPTIONAL: the CAD route from the CSI port through the panel to the bracket is about 7 cm, so the 200 mm 15-to-15 cable in the camera's box reaches with room to fold - this one is the spare. Zero-parcel alternative: Joy-it rb-camera-0.75 at Conrad, 75 cm, 2,93 € |
| Cameras | Trust HD1080p USB webcam (wrist camera) | — | — | 0,00 | ALREADY OWNED | ALREADY OWNED - replaces the 2nd Cam Module 3 AND the CSI-HDMI extender. Lock focus, exposure, gain and white balance before use; check what the model exposes: v4l2-ctl -d /dev/video0 --list-ctrls-menus |
| Display | [Waveshare 4.3in capacitive touch display, DSI, 800x480 (status + fault screen)](https://www.berrybase.de/en/capacitive-touch-display-for-raspberry-pi-dsi-interface-800-480-4.3-inch) | — | — | 0,00 | ALREADY OWNED | ORDERED at BerryBase on 03.10.2026 (owner) - now on hand. verified 10.09.2026; 28 in stock. Uses the Pi 4B's FREE DSI port - the camera is on CSI - and needs no GPIO pins, no separate PSU and no adapter: one 15-pin ribbon carries video, touch and power at 1.2 W, cable included. Alternatives at BerryBase: 7in DSI 49,90 €, Touch Display 2 64,50 €, 3.5in SPI 14,90 € (slow, eats the SPI bus). Render with Pillow to /dev/fb0 - no browser. Keep its light off the platter or it corrupts the strobe speed measurement |
| Display | [Groundmicro FPC cable 1.00 mm pitch 15-pin, 50 cm, for Raspberry Pi CSI/DSI (DSI ribbon Pi -> display)](https://www.welectron.com/Groundmicro-FPC-Cable-100mm-Pitch-15-Pin-for-Raspberry-Pi-CSI-DSI) | 1 | 2,90 | 2,90 | welectron.com | verified 03.10.2026; pick 50 cm in the length selector, 100+ in stock. Re-sourced away from BerryBase. The route is 41 cm, so 50 cm is the right length - the 75 cm Joy-it cable at Conrad (2,93 €) would save the welectron parcel but puts 34 cm of fold and a longer MIPI run behind the display; the 15-pin 1.0 mm Pi standard is what both ends need |
| Vacuum | [Miniature diaphragm vacuum pump 12 V DC, 3 W, ca. 80 kPa](https://funduinoshop.com/en/electronic-modules/valves-pumps/pumps/miniature-diaphragm-vacuum-pump-12v-dc-3w) | — | — | 0,00 | ALREADY OWNED | ORDERED at BerryBase on 03.10.2026 (owner) - now on hand. verified 03.10.2026; was 10,59 € on 10.09 |
| Vacuum | [2/2-way solenoid valve G 1/8 NC, FKM, 12 V, direct acting (DA142426)](https://www.druckluft-fachhandel.de/2-2-wege-magnetventil-g-1-8-stromlos-geschlossen-nc-fkm-12v) | 1 | 42,44 | 42,44 | druckluft-fachhandel.de | verified 10.09.2026; MUST be direct acting - pilot valves do not open under vacuum |
| Vacuum | [Adafruit MPRLS pressure sensor breakout 0-25 PSI, I2C](https://www.berrybase.de/adafruit-mprls-drucksensor-breakout-mit-anschluss-0-bis-25-psi) | — | — | 0,00 | ALREADY OWNED | ORDERED at BerryBase on 03.10.2026 (owner) - now on hand. verified 10.09.2026; OUT OF STOCK. Industrial vacuum switch = 95,30 € |
| Vacuum | [Balgensauger D 40 mm, 1.5 folds, NBR, with G 1/4 fitting](https://morali.de/vakuumsauger/balgensauger/19/bellows-suction-cup-d-40-mm-1-5-folds-with-fit) | 1 | 21,37 | 21,37 | morali.de | verified 10.09.2026; or print the cup lip in TPU per the BOM printed-parts list |
| Vacuum | [Polyurethane tube 6 x 4 mm, natural, per metre](https://www.druckluft-fachhandel.de/polyurethan-schlauch-6-x-4-mm-natur) | 7 | 1,05 | 7,35 | druckluft-fachhandel.de | verified 03.10.2026; docs/04 wants 7 m, the list had 5. Sale price |
| Vacuum | [Anbruchkosten PU tube: cut-length surcharge for less than 50 m](https://www.druckluft-fachhandel.de/polyurethan-schlauch-6-x-4-mm-natur) | 1 | 9,90 | 9,90 | druckluft-fachhandel.de | verified 03.10.2026; charged once per order under 50 m - the 1,05 €/m is a sale price and does not include it |
| Vacuum | [Straight push-in fitting G 1/8 - 6 mm, IQS, -0.95 to 20 bar](https://www.druckluft-fachhandel.de/gerader-steckanschluss-g-1-8-6mm-iqs-standard) | 8 | 1,38 | 11,04 | druckluft-fachhandel.de | verified 03.10.2026; vacuum rated |
| Vacuum | [T-Steckanschluss 6 mm - 6 mm, IQS (push-in tee: pump / valve / MPRLS branch)](https://www.druckluft-fachhandel.de/t-steckanschluss-6mm-6mm-iqs-standard) | 1 | 2,74 | 2,74 | druckluft-fachhandel.de | verified 03.10.2026; DA147495, in stock, 1-3 days. Was missing from the list - the BOM wires the sensor off a tee |
| Sensing | [3x mechanical end-stop with 50 cm cable, 3-pin](https://www.roboter-bausatz.de/p/3er-set-mechanischer-endschalter-mit-50-cm-kabelsatz-3-pin-fuer-cnc-reprap-3d-drucker) | 1 | 3,75 | 3,75 | roboter-bausatz.de | verified 03.10.2026 |
| Sensing | [Mechanical end-stop with 50 cm cable, single](https://www.roboter-bausatz.de/p/mechanischer-endschalter-mit-50-cm-kabelsatz-3-pin-fuer-cnc-reprap-3d-drucker) | 2 | 0,85 | 1,70 | roboter-bausatz.de | verified 03.10.2026; regular price, 0,60 € on sale |
| Sensing | [Hall magnetic sensor module KY-003 (A3144), digital](https://www.berrybase.de/berrybase-hall-magnetic-sensor-module-ky-003-digitaler-ausgang-hall-effekt-arduino-3.3-5v) | — | — | 0,00 | ALREADY OWNED | ORDERED at BerryBase on 03.10.2026 (owner) - now on hand. verified 10.09.2026; 100+ in stock |
| Sensing | [KY-010 photo interrupter / slot optical sensor module](https://www.roboter-bausatz.de/p/ky-010-lichtschranke-modul) | 1 | 1,25 | 1,25 | roboter-bausatz.de | verified 10.09.2026 |
| Deck I/O | [NFKE MG 63 audio cable, 6.3 mm mono jack, 1.8 m (cut one end)](https://www.reichelt.de/de/de/shop/produkt/nf-kabel_6_3_mm_mono_klinkenstecker_gerade_1_8_m_2-pol-109580) | 1 | 1,56 | 1,56 | reichelt.de | verified 10.09.2026; remote start/stop jack |
| Light | [LED strip warm white, 12 V, 5 m (cut to 50 cm)](https://www.reichelt.de/de/de/shop/produkt/led-streifen_warmweiss_5000_mm-235875) | 1 | 5,85 | 5,85 | reichelt.de | verified 10.09.2026 |
| Light | [INFINEON IRLZ44N logic-level MOSFET, N-Ch 55 V 47 A, TO-220](https://www.reichelt.de/de/de/shop/produkt/mosfet_n-ch_55v_47a_110w_to-220ab-129819) | 2 | 0,67 | 1,34 | reichelt.de | verified 10.09.2026; do NOT use IRF520 modules - not logic level |
| Carousel | [Miniature ball bearing 608-ZZ 8x22x7 mm (rollers)](https://www.dold-mechatronik.de/Miniature-ball-bearings-608-ZZ-8x22x7-mm) | 10 | 0,79 | 7,90 | dold-mechatronik.de | verified 10.09.2026 |
| Carousel | [Deep groove ball bearing 6005-2RS 25x47x12 mm](https://www.dold-mechatronik.de/Deep-groove-ball-bearings-6005-2RS-25x47x12-mm) | 1 | 1,79 | 1,79 | dold-mechatronik.de | verified 10.09.2026; cheaper than Kugellager-Express at 2,08 € |
| Carousel | [Precision shaft 25 mm h6, hardened, cut 100 mm (stub shaft)](https://www.dold-mechatronik.de/Precision-shaft-25mm-h6,-ground-and-hardened,-material-CF53-(1.1213),-3.85kg-m,-cut-50-3000mm) | 1 | 3,29 | 3,29 | dold-mechatronik.de | verified 10.09.2026 |
| Cabling | [Energiekette 10x20 R28, open, 1 m (end brackets included)](https://www.cnc-zubehoer.eu/1-m-Energiekette-Schleppkette-leicht-offen-10x20-R28/EK.10x20.R28.o) | 3 | 5,61 | 16,83 | cnc-zubehoer.eu | verified 10.09.2026; cheapest chain found; Dold CK10 is 9,57 €/m plus connectors |
| Cabling | [Dupont Buchsen/Stecker + Crimp Kontakte 650 Teile Set (housings 1x1-2x6, 200 F + 200 M contacts, AWG 16-28)](https://www.roboter-bausatz.de/p/dupont-buchsen-stecker-crimp-kontakte-650-teile-set) | 1 | 6,35 | 6,35 | roboter-bausatz.de | verified 20.09.2026; REPLACES the BerryBase 610-piece set, which is out of stock. Same housing range, more contacts, cheaper, and at a shop already in the order. Crimp tool: the Dupont-type SN-28B (RB) and BerryBase CT-DUP are both out of stock; the SN-01BM at RB (28,65 €) is in stock and crimps Dupont contacts acceptably |
| Cabling | [200-piece jumper wire connector kit, JST-SM / Dupont 2.54 mm](https://www.berrybase.de/en/berrybase-200-piece-jumper-wire-connector-kit-jst-sm-dupont-2.54mm-2-5-pin-male-female) | — | — | 0,00 | ALREADY OWNED | ORDERED at BerryBase on 03.10.2026 (owner) - now on hand. verified 03.10.2026 |
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

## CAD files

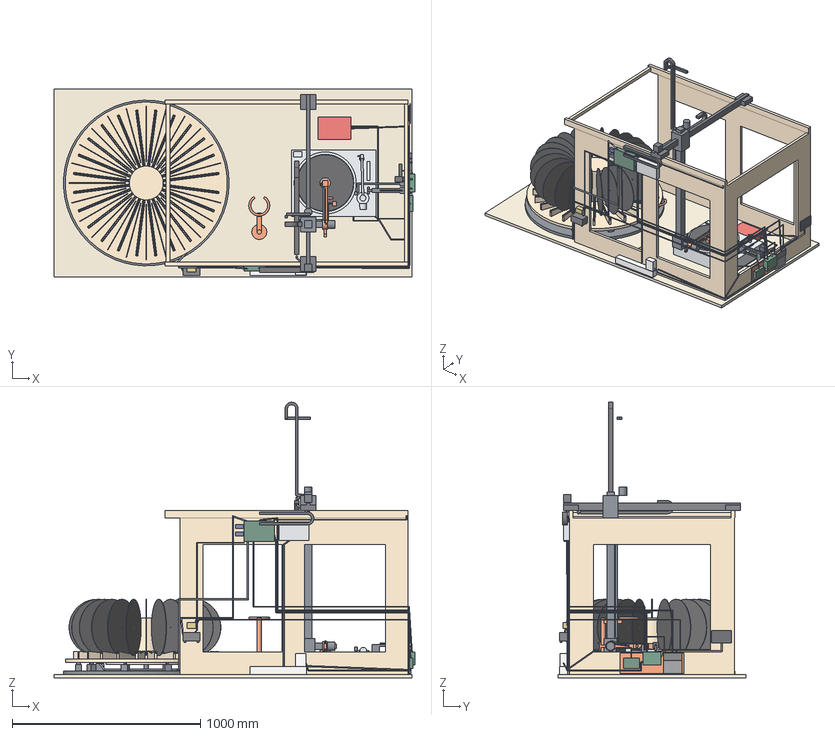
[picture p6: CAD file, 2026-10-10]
cad/export/assembly_place.step
1917.0 x 1000.0 x 1464.0 mm
bench
frame
station
plinth
deck_interface
deck_camera
carousel_base
pcb_octopus
psu_24v
buck_12v
buck_5v
power_strip
psu_pi
pump
valve
pi_plate
pcb_pi
usb_hub
ssd
pcb_relay
pcb_mprls
display_standoffs
display_board
display_glass
scarlett
tonearm
carousel_disc
record_slot1
record_slot2
record_slot3
record_slot4
record_slot5
record_slot6
record_slot7
record_slot8
record_slot9
record_slot10
record_slot11
record_slot12
record_slot13
record_slot14
record_slot15
record_slot16
record_slot17
record_slot18
record_slot19
record_slot20
record_slot21
record_slot22
record_slot23
x_carriage
y_carriage
z_carriage
wrist
column_post
outrigger_cables
wrist_cables
record_held
x_chain
cable_climb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

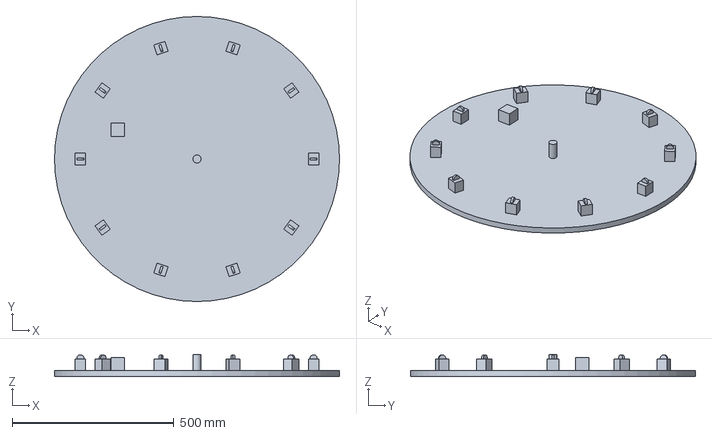
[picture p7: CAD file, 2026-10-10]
cad/export/carousel_base.step
880.0 x 880.0 x 68.0 mm

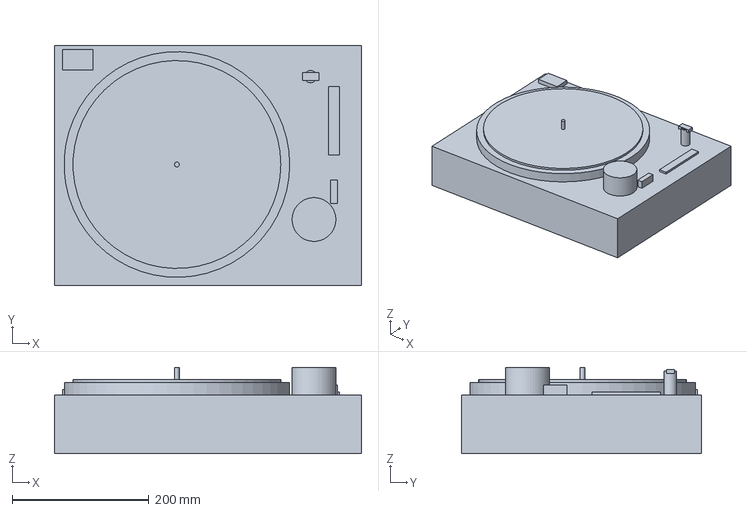
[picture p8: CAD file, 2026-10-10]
cad/export/deck_plinth.step
449.0 x 351.0 x 126.0 mm

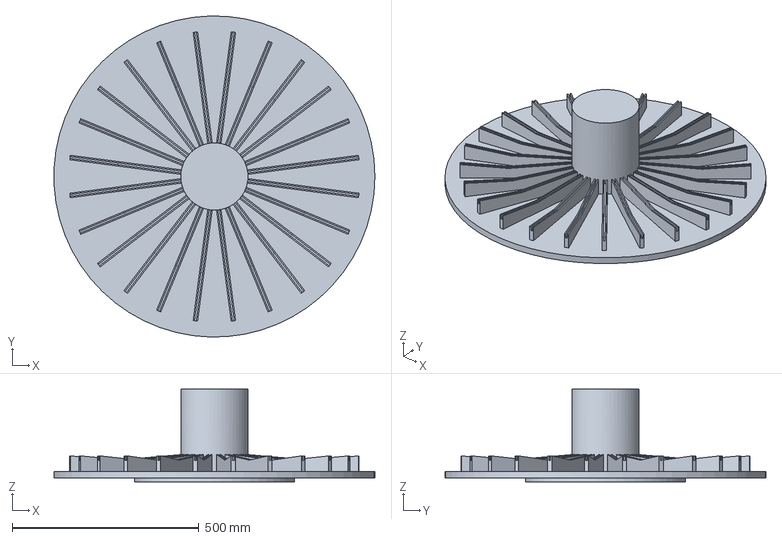
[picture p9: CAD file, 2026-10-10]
cad/export/carousel_disc.step
859.4 x 859.7 x 248.0 mm

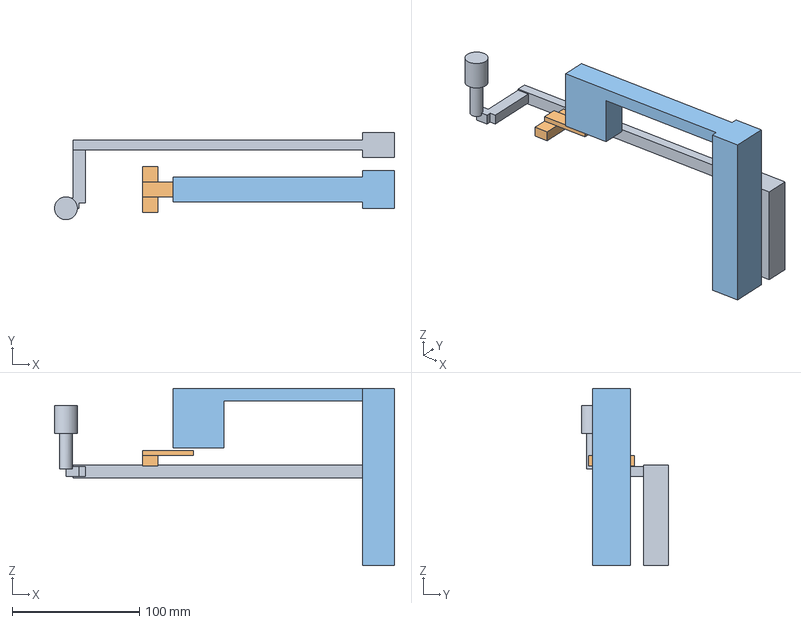
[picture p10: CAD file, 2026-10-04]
cad/export/deck_interface.step
267.4 x 68.7 x 139.5 mm

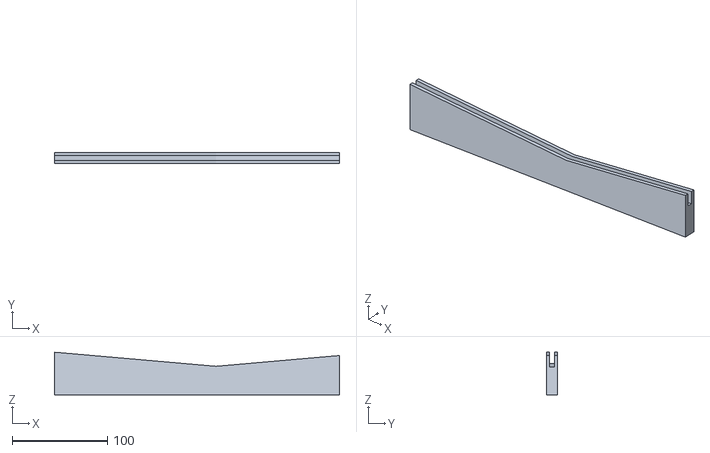
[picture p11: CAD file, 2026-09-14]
cad/export/carousel_comb.stl
300.0 x 12.0 x 44.9

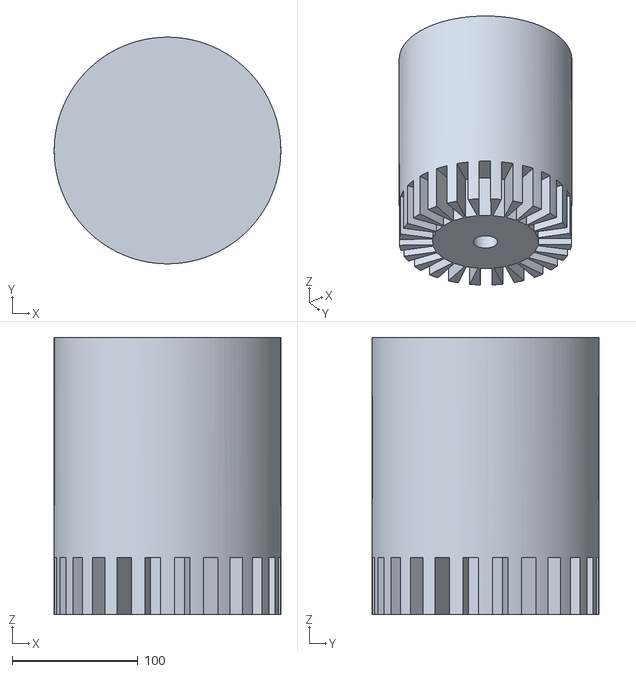
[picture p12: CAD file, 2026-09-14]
cad/export/carousel_hub.stl
180.0 x 180.0 x 220.0

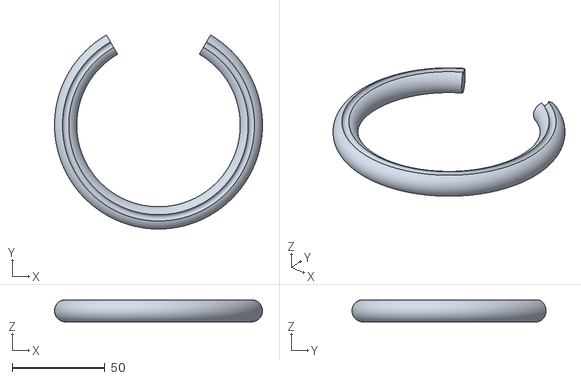
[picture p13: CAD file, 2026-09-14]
cad/export/station_ring_rest.stl
112.0 x 104.5 x 11.8

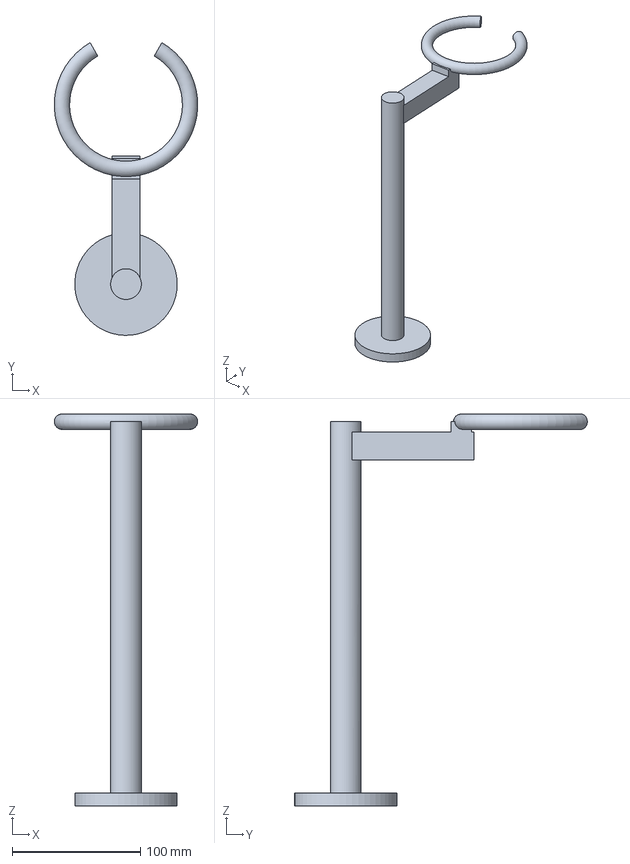
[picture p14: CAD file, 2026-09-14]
cad/export/station.step
111.9 x 228.5 x 306.0 mm

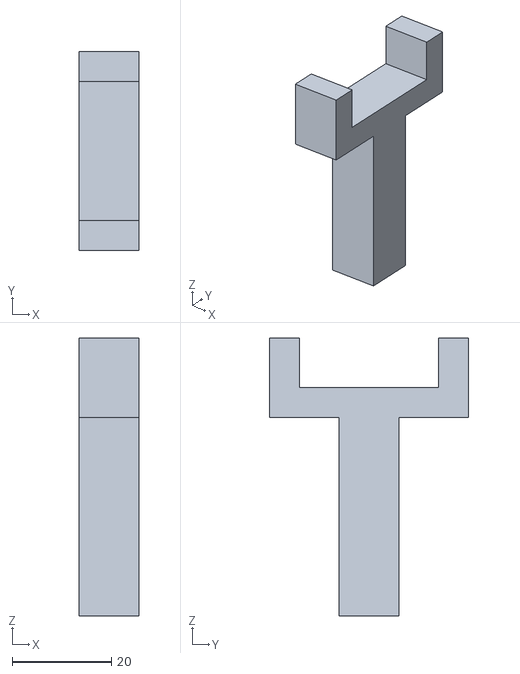
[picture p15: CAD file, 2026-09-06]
cad/export/wrist_fork.stl
12.0 x 40.0 x 56.0

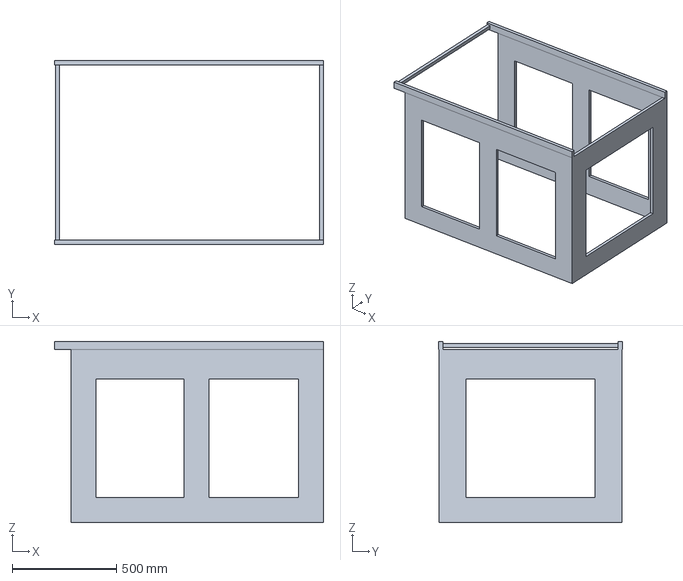
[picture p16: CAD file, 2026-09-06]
cad/export/frame.step
1290.0 x 880.0 x 870.0 mm

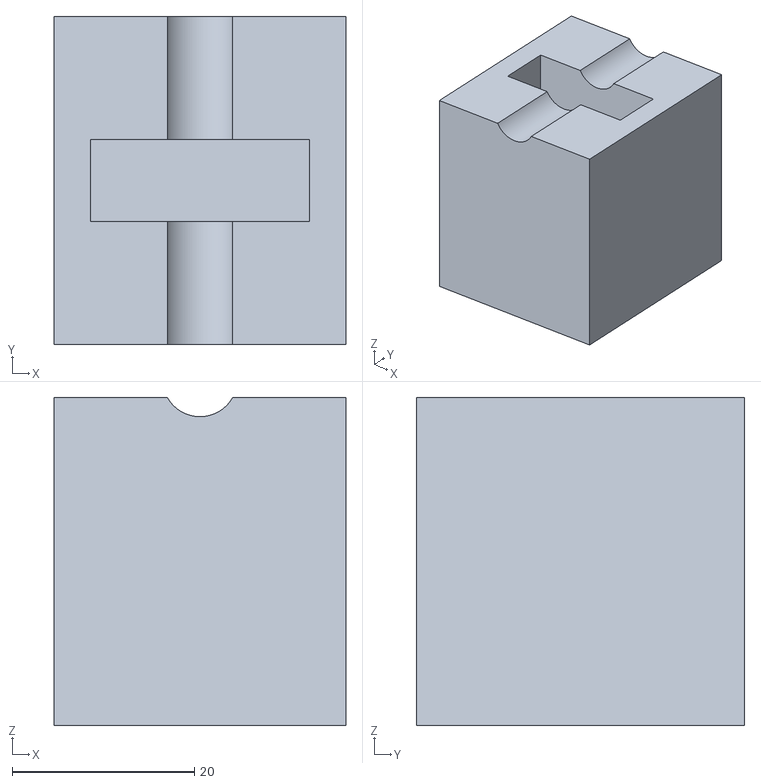
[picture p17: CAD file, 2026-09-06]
cad/export/carousel_roller_bracket.stl
32.0 x 36.0 x 36.0

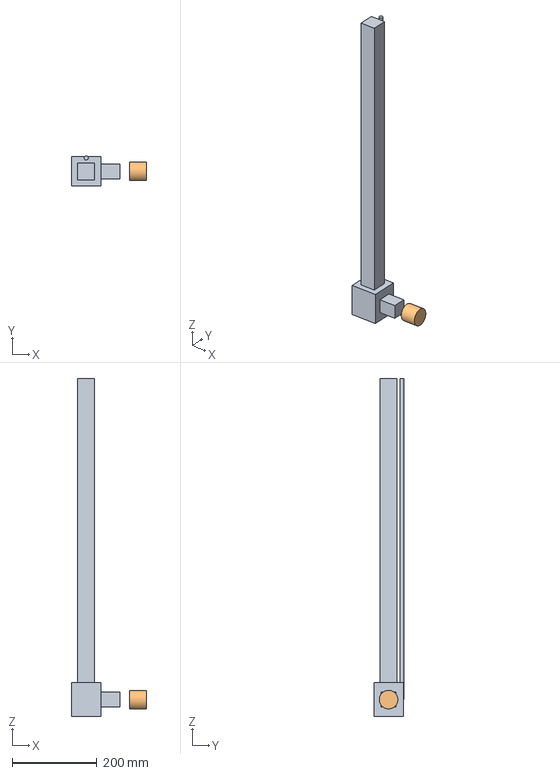
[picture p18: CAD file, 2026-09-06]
cad/export/gantry_z_carriage.step
178.0 x 72.0 x 800.0 mm

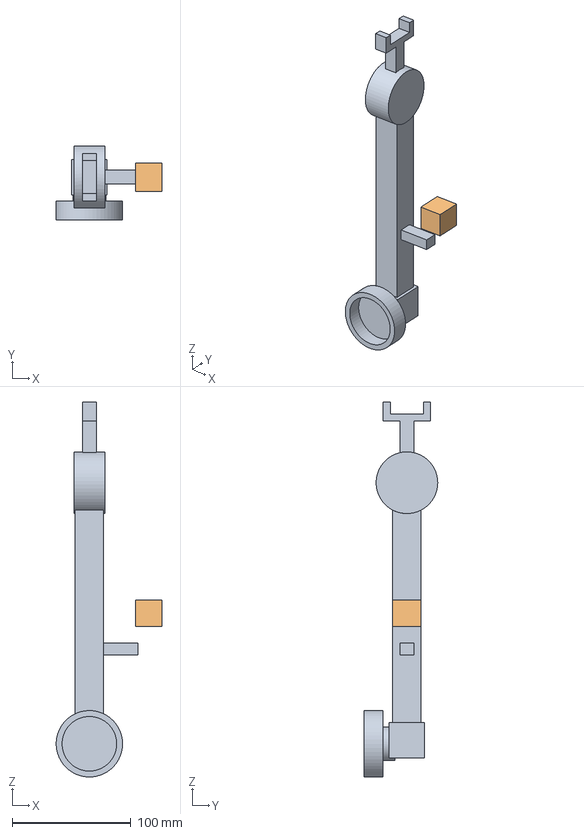
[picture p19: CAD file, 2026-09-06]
cad/export/gantry_wrist.step
88.9 x 62.0 x 316.0 mm

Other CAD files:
cad/export/assembly_regrip.step

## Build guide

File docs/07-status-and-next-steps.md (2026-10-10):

# Status and next steps

Written 6 September 2026, at the end of the concept phase; the section at the end brings it to 14 September.

## Where the project stands

The concept is complete and has been reviewed step by step against an interactive model (`concept-model.html`) that plans every motion of the cycle as waypoints. Every subsystem has a defined mechanism, every step of the cycle has a defined sequence, and every decision and rejected alternative is written down in `05-design-decisions.md`. A first parametric CAD exists under `cad/` (CadQuery), with STEP exports of the whole machine and the sub-assemblies, STL files of the first printed parts, and a collision checker that sweeps the complete cycle; it passes with zero intersections at 20 mm / 5° sampling. Nothing has been bought, cut or printed. There is no machine code yet.

The machine, in its final concept form: a 24-slot carousel magazine with records standing as spokes; an OSB box frame carrying an XYZ gantry on V-slot with a rotary wrist; a single vacuum cup on the label as the gripper, with a camera and a finger-lift fork on the same wrist; a passive ring rest for the side-B flip and the label photos; the Omnitronic DD 3120 as the deck, worked through its remote start/stop jack, its 33/45 buttons and its cue lever; a second camera and a 50 Hz LED strobe facing the headshell; Klipper on a printer mainboard for motion, a Raspberry Pi 4B for orchestration, vision, the web interface and recording through the Focusrite Scarlett. No brush; records are cleaned by hand before loading. No automatic recovery from a skip; the arm lifts, the platter stops, and the machine waits.

## Decisions taken during the review, in order

The stacking changer was rejected for distortion; a gantry was chosen over an arm; the rim gripper gave way to a vacuum cup on the label so that 10", 7" and shaped records work; the linear infeed and outfeed racks gave way to a round magazine with the record returning to its own slot; the wrist axis turned to X so the cup approaches a spoke along Y; the flip became a passive ring rest off the centreline; the Z tower became a moving column; the fork moved onto the wrist opposite the cup; the label camera moved onto the wrist and the deck camera down to platter height facing the headshell; the deck's own cue lever, worked by a servo, took over all lifting, with the platter stopped for every placement and removal; the servo bracket gained an end-stop pin so the stylus can never reach the label; speed is set by the deck's buttons, not by resampling, because of RIAA; a crystal-timed LED strobe measures platter speed on any deck; the aluminium frame became plywood with V-slot beams; the lazy susan became a roller ring of 608 bearings; the brush module was dropped; an automatic turntable was rejected because of locked grooves, inside-out sides and non-standard start and end positions; V-slot replaced linear rails on X and Y; a used printer became the intended parts source; the deck's start/stop jack and speed buttons are switched by the Conrad USB relay card already on hand; the MIMXRT1010-EVK was ruled out as a Klipper MCU.

## Already on hand

The Omnitronic DD 3120 (and a Stanton T.92 USB as spare), the Focusrite Scarlett, the Conrad Components 393905 USB relay card, an Ortofon DJ S cartridge, two Raspberry Pi 4B rev 1.1 / 2 GB with supplies and cards, an external USB 3.0 SSD, a self-powered USB 3.0 hub, a Logitech C270 and a 1080p USB webcam, and the 3D printer. Ordered at BerryBase on 3 October: the Pi camera, the status display, the Armor shell for the Pi, the vacuum pump, the MPRLS, the Hall sensor and the JST kit. Bought on 6 October: an Ender 3 V2 as the donor printer. Not yet: the extrusion, the Z rail, the geared motors, the controller board. The full list with where each item goes is in `08-assembly-instructions.md`.

## What to buy and do first

The order below front-loads the things that could still change the design, so that nothing expensive is bought on an assumption.

First, measure the DD 3120 with a ruler and record the numbers in `01-design-specification.md`. The outline, the platter's height, the spindle, the arm pivot and the cue lever's travel are done (4 October; the numbers are in the specification); what remains is the arm rest's position, the cue lever's force and whether it holds both positions, the heights of the lever's top, the arm tube and the finger lift above the case, the finger lift's shape, and where the end-stop pin has to stand for the real, S-shaped arm. Check the remote jack's behaviour (held or toggle) with a paper clip, measure the voltage across the 33 and 45 switches, find out what the pitch output carries, and swap the felt slipmat for a rubber or cork mat.

Second, buy the 3D printer, since it is needed for everything after this point, and then a used donor printer for motors, PSU, wheels, belts and a possible controller board. The donor is bought: an Ender 3 V2, on 6 October, arriving the week of 12 October. Run it once before stripping it, note the board revision and the MCU marking (an STM32F103 or a GD32 clone, which needs different Klipper build options), and count the wheels and eccentrics against the 12 and 6 the build needs before ordering the rest of the donor route.

Third, print and test the three parts that decide the geometry before any frame exists: the finger-lift fork on a hand-held handle against the real headshell; the vacuum cup bracket with a hand pump against 12", 10", 7" and picture-disc labels; and three carousel combs with the hub, to confirm the 6.5 cm gap takes the wrist assembly and that a 12", a 10" and a 7" each roll to the apex of the V. A Raspberry Pi with one camera can be set up in parallel to prove hole and groove-band detection on a record lying on a table.

Fourth, detail the CAD: put the measured deck numbers into `cad/params.py`, rerun the collision sweep, then turn the remaining printed parts from envelopes into print-ready parts in the order the build needs them (wrist and cup end, carousel hub and combs, Z carriage, station, cue bracket).

Fifth, the software, which can begin before the machine is complete: the Klipper configuration and macros, the orchestrator's state machine and motion planner (the same one the concept model uses), the vision routines, and the web interface with the batch manifest. The step-through mode of the web interface is the commissioning tool.

## What the CAD changed

Building the CAD and sweeping the cycle changed four numbers and one rule against the concept: the frame is 86 cm wide instead of 80, the finger-lift fork is 55 mm long instead of 100, the end-stop pin stands 45 mm from the arm pivot instead of 60, the wrist camera sits 110 mm up the outer side of the arm and no longer looks at records inside the carousel, and the carry to the station swings the record to vertical before moving in Y. All are in the specification and the decision log.

## Repository

`main` is the trunk and every change reaches it through a pull request on its own branch; CI runs ruff, markdownlint and the collision sweep on each one. A `v*` release tag publishes the documentation site. The workflow is written down in `.claude/CLAUDE.md`.

## Since 6 September

The sourcing pass of 10 September priced every line of the bill of materials against live German shops and corrected it: the cue-lever servo is an MG996R on the printed pusher rod, the vacuum sensor is an Adafruit MPRLS, the solenoid valve has to be direct-acting, and Motedis is out because it carries no V-slot. The machine runs on a Raspberry Pi 4B already on hand, which fixed one CSI port and put a USB webcam on the wrist. A consistency check against the CAD then found the concept's 80 cm frame surviving in three cut lengths, one plywood sheet where two are needed, no 12 V supply for three 12 V parts, and a Y travel of 63 cm where the concept said 45. `08-assembly-instructions.md` came out of that, with every cable's routed length.

Three decisions were taken on 14 September and are in `05-design-decisions.md`: the electronics sit on the frame rather than in a box; the ring rest is 100 mm in mean diameter at the label's edge with an O-ring on top; and the grip check lives in the orchestrator, on the MPRLS alone. The collision sweep after the geometry changes reports 831 samples and 0 collisions. Nothing is left in `06-open-questions.md` that is a decision rather than a measurement.

The carousel then learned to hold 10" and 7" records, which the concept had promised and the CAD had never delivered: the rim ring is gone and each comb's slot floor is a V with its apex at the pick radius, so every size rolls to the same centre line and is picked at its own height; the planner and the collision sweep take the size as a parameter. The sweep found the wrist hub and the column's foot below a 12" neighbour's edge at a 7" pick, so a 7" must have a 7", a 10" or nothing in the slot on its front side, a rule the manifest editor will enforce. Shaped and off-centre discs, which have no round edge to roll on, are placed on the platter by hand from a "by hand" line in the manifest.

The electronics, the three cable chains and every cable and hose run are now in the CAD as well, at the places `08-assembly-instructions.md` gives them, and the documents carry views rendered from the model. Drawing them moved the X motor to the rear end bracket beside the X chain and stood the Z chain above the guide block instead of hanging it beside the column. The web viewer and the renders now carry all three record sizes: the carousel holds a mixed load, the viewer plays the cycle for whichever size is selected, and `02-operating-cycle.md` shows the cycle as an animation rendered from the model. A flip-free alternative, one side per run with the user turning the records between runs, was weighed and kept as a mode rather than a design: the flip station stays, the manifest gains a "one side per run" switch, and whether the re-grip earns its keep is now a question for the first batches. Still nothing has been bought, cut or printed; the order of work above stands.

On 3 October every priced line was fetched again. The Octopus V1.1 and the plain 17HS4417P1 had been discontinued at roboter-bausatz, so the board now comes from 3DJake and the steppers are the -X4 cable variant of the same motor. The shopping list had never absorbed the September errata, so it gained the 12 V buck, the tee, both USB cables and the extension wire, and the corrected beam lengths, wheel count and tube length. Plywood was the largest error in the bill of materials: 120 € for two sheets became about 273 € for a birch sheet for the panels and an MDF sheet for the discs, with cheaper panel materials priced as alternatives on a new Hornbach sheet. A cable check against the CAD routes made the wrist camera's USB an active 5 m repeater from the Pi's hub. Two additions: a 4.3″ DSI status display on the deck-end panel, and the decision that a record's identity comes from the manifest, not the label photograph, which opens the question of what catches a mis-loaded magazine. The BerryBase part of the order has been placed.

On 4 October the panel material was decided: OSB 3 from two shelf-stock sheets instead of a birch sheet on a five-week order, with a steel angle in each inside corner, M4 T-nuts for every removable part and penny washers under the beam bolts to make up for OSB's weak edges. The discs stay MDF. Wood and metal come to about 137 € instead of 273 €.

The deck was then measured with a ruler, also on 4 October: 44.9 × 35.1 × 8.6 cm, the platter 1.8 cm above the case, and the spindle, the arm pivot and the cue lever placed from the deck's edges. The photo had been off by 5 to 20 mm on each. The one measurement that changed the design is the lever: its top travels 24 mm front to back, not along X, so the pusher rod from the end panel is gone and the servo hangs over the lever on a beam with a yoke on its horn. The arm angles now follow from the pivot and the stylus radii instead of being typed in. The collision sweep reports 1301 samples and 0 collisions.

On 10 October the model caught up with the parts. The status display is in the CAD on the deck-end panel's front post, on standoffs at the Pi's hole pattern with its 0.4 m DSI ribbon from the Pi; the Pi is drawn in its finned aluminium shell; its 15 W supply is a wall plug in the power strip, with its USB-C lead round the corner to the Pi; and the wrist camera's USB run from the hub to the X chain is drawn. The carousel base plate is 18 mm, the thickness of the MDF it is cut from, where the model had 15, so the disc and every pick height sit 3 mm higher; the turntable mat is the 4 mm cork the Hornbach sheet buys. The donor printer, an Ender 3 V2, was bought on 6 October for 55 €. The collision sweep reports 1301 samples and 0 collisions.

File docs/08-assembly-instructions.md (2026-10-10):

# Assembly instructions

How the machine goes together, in the order it has to, with every part named: bought, printed, cut from sheet material, picked up at the Baumarkt, or already on hand. Dimensions come from `../cad/params.py`, which is the authority; where this document gives a number, that is where it came from. Nothing here has been built yet, so treat the sequence as a plan to be corrected on the first pass and written back.

Read `07-status-and-next-steps.md` first. It front-loads the things that can still change the design — measuring the deck, printing the three parts that decide the geometry — and none of the work below should start before those are done.

## Already on hand

Nothing in this table is bought. Everything in it has a place in the build.

| Item | Goes | Notes |
|---|---|---|
| Omnitronic DD 3120 turntable | On the bench under the deck end of the frame | Swap the felt slipmat for rubber or cork before the first record. The Stanton T.92 USB stays a spare and is not used |
| Ortofon DJ S cartridge | On the deck's headshell | Spherical, tracks at about 3 g; the right stylus for commissioning |
| Focusrite Scarlett | Beside the deck | USB to the powered hub, not to the Pi. The deck's line output feeds it; the Scarlett has no phono input |
| Conrad 393905 USB relay card | With the Pi group on the outside of the deck-end panel | Channel 1 to the deck's remote jack, channels 2 and 3 across the 33 and 45 buttons |
| 2 × Raspberry Pi 4B rev 1.1, 2 GB, with 15 W supplies and 32 GB cards | One runs the machine; the other is the cold spare, kept boxed | rev 1.1 refuses e-marked USB-C cables: use the official supply. The card holds the OS only, never a recording |
| External USB 3.0 SSD | With the Pi | Every WAV goes here. About 860 MB per side, about 40 GB per full magazine |
| Self-powered USB 3.0 hub | With the Pi | The Scarlett, the SSD, the wrist camera and the relay card all hang off it; the Pi's own ports budget about 1.2 A across all four |
| Logitech C270 webcam | On the wrist | The wrist camera. Fixed focus, set once by hand at the working distance over a label, then focus, exposure, gain and white balance locked |
| 1080p USB webcam | Kept | The fallback for the wrist if the C270 fails or turns out not to resolve the centre hole and the groove bands; the label photographs no longer decide anything, since a record's identity comes from the manifest |
| 3D printer | Prints every part in the printed-parts table | PETG for structure, TPU wherever a record is touched |
| 2 × RCA to 2 × 6.3 mm jack lead | From the deck's line output into the Scarlett | The audio path; confirmed on hand on 3 October |
| Multimetrix DMM105 multimeter | On the bench while wiring | Sets the two adjustable bucks and checks the button taps. An old meter wants two checks first: a fresh battery, and its reading against a known source, such as the 5 V of a USB port, before a buck is trusted to it |

## Panels and discs

The panels are 18 mm OSB 3 and the two carousel discs 18 mm MDF, which is flat and cheap and carries under 5 kg of records. OSB is stiff enough for the box but weak at its edges and under screws that come out again, so steel and T-nuts take those jobs; see the frame step and `05-design-decisions.md`. None of the cuts needs to be better than a few millimetres — every position that matters is carried by a printed or bought part that registers to the wood — but the carousel disc wants to be flat, so take it from the middle of a sheet, not an edge that has been standing in a corner.

| Piece | Size (mm) | Qty | Cut-outs |
|---|---|---|---|
| Side panel | 1210 × 830 | 2 | Two windows, each about 420 × 570, leaving a 120 mm strip along the bottom, a 140 mm strip along the top, 120 mm posts at both ends and one at 380 mm from the carousel end |
| End panel | 842 × 830 | 1 | One window about 620 × 570, same strips, 120 mm posts at both sides. 842 is the width between the side panels' inner faces; it sits between them, at the deck end |
| Carousel disc | Ø 860 | 1 | Ø 26 hole at the centre for the stub shaft bore of the printed hub. Cut with a jigsaw against a trammel; rough is fine, the printed hub and combs carry the geometry |
| Carousel base plate | Ø 880 | 1 | The stub shaft and ten roller brackets bolt to it; a Ø 25 hole at the centre if the shaft is through-bolted |
| Bench top | 1900 × 1000 | 1 | Only if there is no bench. An existing bench of about that size does the job |

**Sheets.** Two 2500 × 1250 OSB sheets for the panels: the two side panels stack on the first (1210 × 1660), and the end panel (842 × 830) comes from the second, which leaves about 1.1 m² of offcut for the deck stop, the feet and test pieces. The two discs need 880 × 1740 between them and fit one 2440 × 1220 MDF sheet with 700 mm to spare. All three sheets are shelf stock at Hornbach; the prices are in the [shopping list](../sourcing/bom-shopping-list.md#hornbach-local). A bench top is a further sheet, or spruce, or the bench that is already there. Have the Markt cut the panels to their rectangles and the MDF into an 880 and an 860 square, so nothing larger than 1210 × 830 has to travel, and check that the 880 square fits the car; the windows and the circles are jigsaw work at home.

**Windows.** Drill a 20 to 26 mm hole in each corner first, so the jigsaw never has to turn in OSB and the corners come out round, which stops both chipping and cracks; then jigsaw between them, and do not bother with a clean edge: the windows exist so the interior stays open, and nothing registers to them. Sand the edges where hands will go.

## Baumarkt

What the bill of materials leaves to a local shop, on top of the sheet material. The [shopping list](../sourcing/bom-shopping-list.md#hornbach-local) prices all of it at Hornbach, with article numbers; two items are not stocked there and go on an online order instead, the O-ring (on the druckluft-fachhandel order) and four M4 rubber-metal buffers for the pump mount.

- Wood glue, D3, one 250 g bottle. The frame is a glued box; the screws are clamps.
- Steel angle, 25 × 25 × 3 mm, one 2 m length, cut into two 830 mm corner posts.
- M4 T-nuts (Einschlagmuttern), about 20, and M4 × 30 socket-head screws, for every part on the panels that comes off again: the controller plate, the Pi plate, the cue-servo and camera brackets, the display mount and the pump mount.
- Penny washers, DIN 9021 for M5, under the heads of the beam bolts on the panels' outer faces.
- Wood screws: 4 × 40 mm, about 40, for the panel joints and the beam blocks; 3.5 × 25 mm, about 60, for printed parts that stay put; 3.5 × 16 mm, about 40, for the roller brackets and small brackets. Countersunk, Torx.
- Sanding: 80 and 120 grit, one sheet each; a block.
- Four rubber feet or adjustable levelling feet for the carousel base plate, so it stands flat on a bench that is not.
- One rubber O-ring, 3 mm cord, about 97 mm inside diameter (95 × 3 stretches on), NBR: it sits in the groove on top of the ring rest and is what the record actually rests on.
- Cable ties, 100 × 2.5 mm, one bag; and a few cable tie mounts with adhesive backs.
- Fabric or Kapton tape for holding cable bundles in the chains while they are dressed.
- Double-sided tape or hook-and-loop for the Pi and relay card if they are not screwed down.
- A rubber or cork turntable mat if the deck's felt slipmat is the only one there. A 4 mm cork sheet is cheap and is what the CAD draws; a mat of another thickness wants `MAT_T` changed, see `06-open-questions.md`.
- Thread locker, medium strength (Loctite 243), for the pulley grub screws and the stepper mounts.
- Optional: a small can of clear wax or oil for the panels, and a 40 mm hole saw for the cable exits through the panels.

Tools, if they are not there already: a jigsaw with a wood blade, a cordless drill with a 4 mm, a 4.5 mm and an 8 mm bit, a 20 to 26 mm Forstner bit and a countersink, a hacksaw for the steel angle, a long straightedge and a square, four clamps of at least 90 cm reach or strap clamps, hex keys 2 to 5 mm, a set of small spanners, a soldering iron with a heat-set insert tip for the M3 inserts, a multimeter, wire strippers and flush cutters, T15 and T20 Torx bits for the wood screws, a crimp tool for JST-XH contacts, which are what the Octopus's motor and end-stop headers take, and Dupont (an SN-01BM does both), a heat gun for the shrink tube, digital calipers, and a spirit level.

## Printed parts

PETG unless marked TPU. The CAD marks which parts have their functional features and which are still envelopes to be detailed as the build reaches them; do not print an envelope. Print the geometry-deciding parts first, as `07-status-and-next-steps.md` says: the fork, the cup bracket and three combs with a hub, before any frame exists.

| Assembly | Part | Qty | Material | In the CAD |
|---|---|---|---|---|
| Carousel | Centre hub, 24 comb sockets and the 25 mm shaft bore | 1 | PETG | Print-ready |
| Carousel | Slot comb: the 5 mm locating slot on a V floor, 5° each way, apex 260 mm from the axis | 24 | PETG | Print-ready |
| Carousel | GT2 tooth-ring segment, dovetailed, 45° each | 8 | PETG | Envelope |
| Carousel | Roller bracket for one 608 bearing | 10 | PETG | Print-ready |
| Carousel | Index stepper mount with the 20T pulley position | 1 | PETG | Envelope |
| Carousel | Home-mark flag and the slot-sensor mount | 1 + 1 | PETG | Envelope |
| Gantry | X carriage V-wheel plate, 4 wheels each | 2 | PETG, or the donor's aluminium plates | Envelope |
| Gantry | Cross-beam end bracket, joins the cross beam to each X plate | 2 | PETG | Envelope |
| Gantry | X motor mount and the two belt idler mounts | 1 + 2 | PETG | Envelope |
| Gantry | Y wheel plate under the guide block, 4 wheels | 1 | PETG | Envelope |
| Gantry | Z guide block, rides the Y plate, carries the Z motor and the column's guide | 1 | PETG | Envelope |
| Gantry | Z carriage block with the 90 mm outrigger | 1 | PETG | Envelope |
| Gantry | Lead-screw nut holder | 1 | PETG | Envelope |
| Gantry | Column end caps | 2 | PETG | Envelope |
| Gantry | Cable-chain end brackets, X, Y and Z | 6 | PETG | Envelope |
| Wrist | Hub with the bearing seats and the stepper coupling | 1 | PETG | Envelope |
| Wrist | Arm, 220 mm, with the cup bracket at its end | 1 | PETG | Envelope |
| Wrist | Cup bracket, kept above the cup so the spindle tip meets nothing | 1 | PETG | Envelope |
| Wrist | Hose clips along the arm | 3 | PETG | Envelope |
| Wrist | Wrist camera mount, outer side of the arm, 110 mm up | 1 | PETG | Envelope |
| Wrist | Finger-lift fork, 55 mm, with prongs 28 mm apart | 1 | PETG | Print-ready |
| Wrist | Fork lining | 1 | TPU | To be added to the fork |
| Wrist | Hall sensor mount at the hub | 1 | PETG | Envelope |
| Station | Ring rest, 100 mm mean diameter, with the O-ring groove on top | 1 | PETG | Print-ready |
| Station | Post foot, screwed to the bench | 1 | PETG | Envelope |
| Electronics | Controller plate for the outside of the rear panel: Octopus on standoffs, the supply, both bucks | 1 | PETG | Envelope |
| Electronics | Pi plate for the outside of the end panel: Pi, hub, SSD, relay card, MPRLS | 1 | PETG | Envelope |
| Electronics | Pump and valve mount on rubber feet | 1 | PETG | Envelope |
| Deck interface | Cue-servo post and beam off the end panel, the MG996R hanging from the beam's end over the lever | 1 | PETG | Envelope |
| Deck interface | Yoke on the servo horn, straddling the lever's top | 1 | PETG or TPU | Envelope |
| Deck interface | End-stop bar and pin base | 1 | PETG | Envelope |
| Deck interface | End-stop pin sleeve | 1 | TPU | — |
| Cameras and light | Deck camera bracket on the end panel | 1 | PETG | Envelope |
| Cameras and light | LED bar housing | 1 | PETG | Envelope |

About 30 distinct parts and 50 to 70 hours of printing. The 24 combs and 10 roller brackets are the bulk of it and are also the ones to print first, because the carousel is the one sub-assembly that can be built and tested before anything else exists.

## Assembly order

Each sub-assembly is built and checked on its own before it meets the next. The order is the order of dependence: the carousel needs nothing else; the frame needs nothing else; the gantry needs the frame; the wrist needs the gantry; everything electrical needs everything mechanical to be where it will stay.

### 1. Carousel

Bolt the stub shaft to the centre of the base plate, upright, and press the 6005 bearing onto it. Screw the ten roller brackets to the base plate on a 720 mm circle, 36° apart, each with its 608 bearing on an M4 axle, all pointing radially; a paper template printed at 1:1 puts them close enough, because the disc only rests on them. Stand the base plate on its feet and level it.

Drill the Ø 26 hole in the centre of the disc. Screw the hub to the top of the disc, centred on the hole, and lower the disc onto the shaft so the hub's bore takes the bearing. Spin it: it should turn on the rollers with no rock. If it rocks, one roller bracket is high; a washer under its neighbours fixes it.

Push the 24 combs into the hub's sockets and screw each comb's outer end to the disc; the hub sets the 15° pitch, the comb slots set the record plane, and the V floors set the pick radius. Leave the slots bare: a record's edge has to roll along the V to its apex, and felt or a soft lining there would hold it wherever it landed. Fit the eight tooth-ring segments to the underside of the disc, dovetails engaged, on the 215 mm radius. Screw the index stepper mount to the base plate at the tooth ring's edge, with the geared NEMA17 and its 20T pulley meshing the ring, and fit the home-mark flag on the disc and the slot sensor on the base plate so the flag passes through it once per turn.

Stand three records in three adjacent slots and check the gap at the label radius with a ruler: about 65 mm between faces. If it is less, `06-open-questions.md` has the fallback. Then drop a 12", a 10" and a 7" in turn into one slot, anywhere along its length, and measure where each comes to rest: the centre should be 260 mm from the axis every time, within a millimetre, and 247, 222 and 184 mm above the bench. A record that stops short needs a steeper V, one number in `cad/params.py`.

### 2. Frame

Before assembly, press the M4 T-nuts into the panels from the far face at every position where a part will come off again; it is far easier with the panels flat on the bench. Glue and screw the two side panels to the end panel, end panel between the sides, square on the bench top. Clamp, check the diagonals, let the glue cure. Then fit a steel angle the full 830 mm height into each of the two inside corners, drilled 4.5 mm and countersunk every 120 mm, screwed into both panels with 3.5 × 16 screws: the screws into the end panel's edge hold poorly in OSB, and the angle is what actually holds the corner. Screw a block of offcut into each of the three lower corners as a foot if the bench is not flat.

Bolt a 1290 mm 2040 V-slot beam along the top edge of each side panel with its 40 mm face vertical and the slot facing the other beam, overhanging the open carousel end by 80 mm, using M5 bolts through the panel into T-nuts, with a penny washer under each bolt head so it does not pull into the OSB. Shim until the two beams are parallel and in one plane — this is the one alignment that matters on the whole frame, because the X carriages ride in these slots; a long straightedge across both beams, checked at three points, is the test. Bolt the 2020 tie across the open end, 880 mm long over the beams, so they stay parallel under load.

### 3. X axis

Build the two X carriage plates: four Delrin V-wheels each, two on fixed spacers and two on eccentrics, so the plate can be pinched onto the beam. Set each plate on its beam and adjust the eccentrics until it rolls the full 1290 mm with no rock and no binding. Join the plates with the 940 mm 2040 cross beam through the end brackets. The cross beam is 940 because the frame is 860 wide over the panels and the plates sit on the beams outside them; an 800 mm beam, which is what the concept had, does not reach.

Fit the X motor on the rear end bracket, next to where the X chain arrives, an idler on the front one, and run the GT2 belt along the outside of the rear X beam: fixed at both beam ends, wrapped round the motor pulley and its idler on the carriage. Tension by hand until it hums when plucked. Fit the X end-stop at the deck end of the beam.

### 4. Y axis

Build the Y wheel plate — four wheels, two eccentric — and set it on the cross beam. Screw the Z guide block to it. Fit the Y motor on one end bracket of the cross beam, an idler at the other, and run the belt fixed at both ends of the cross beam, round the pulley and idler on the Y plate. Fit the Y end-stop on the cross beam at the rear.

The planner uses 625 mm of Y travel, not the 45 cm the concept assumed: the re-grip poses reach from −340 mm to +285 mm. With 80 mm plates at both ends and an 80 mm guide block, the 940 mm cross beam gives about 700 mm, so it fits, but it means the Y cables need a chain of their own along the cross beam, not a loop.

### 5. Z column

Bolt the 800 mm MGN12 rail to the 760 mm column and its carriage into the guide block, so the column slides through the block. Fit the KFL08 bearing at the top of the column, the lead-screw nut holder on the guide block, and the T8 screw through them, coupled to the Z motor on the guide block. The column carries the screw; the nut is fixed; turning the screw lifts the column. Fit the end caps, and the Z end-stop on the guide block so the column trips it at its top. The cycle uses 430 mm of Z; the screw and rail have room for 600.

### 6. Wrist

Bolt the Z carriage block to the bottom of the column and the wrist hub to the end of its 90 mm outrigger, on the +X side, with the geared NEMA17 driving the hub through the coupling. Fit the arm to the hub pointing down, the cup bracket at its end, the bellows cup on its neck facing −Y, and the fork on the hub opposite the arm, pointing up. Fit the camera mount 110 mm up the arm on the +X side and the C270 in it, looking along the cup's axis. Fit the Hall sensor at the hub and its magnet on the arm at the hanging position.

Before the wrist goes on the machine, test the cup end by hand: 12", 10", 7" and a picture disc, held by their labels with a hand pump. Test the fork on a handle against the real headshell's finger lift. Both are in `07-status-and-next-steps.md` as the first things to print, and both have to pass before the frame is worth building.

### 7. Flip station

The ring rest stands on a post on a printed foot screwed to the bench, at X = 200 mm, Y = −120 mm, Z = 300 mm, with its 60° opening towards the front. Screw the foot to the bench, the post into the foot, the horizontal arm to the post so it runs under the ring and never touches a record on it, and the ring to the riser. Seat the O-ring in the groove on top; it stands a millimetre proud and the record rests on it, not on the print. The ring is 100 mm in mean diameter, so it holds a record at the edge of its label: a 7" overhangs it by 32 mm, the cup has 16 mm to its inner edge, and the arm passes through the 60° opening with 10 mm a side.

### 8. Deck interface

Set the deck on the bench inside the frame with its spindle at X = 550, Y = 0, and screw an offcut stop against two of its feet so it goes back to the same place after every lift-out. Measure everything `07-status-and-next-steps.md` says to measure before this point; the bracket positions below depend on those numbers.

Fix the cue-servo post to the inside of the end panel's bottom strip, in line with the middle of the lever's travel, with its beam reaching out over the right edge of the deck and the MG996R hanging from the beam's end, shaft down, 28 mm to the right of the lever. Fit the yoke to the horn so it straddles the lever's top with a millimetre of play, and set the servo's two angles in `printer.cfg` by hand: the lever's top travels 24 mm front to back, about 25° of horn either side of the middle, and the angles must stop short of the lever's own stops at both ends so the servo never stalls against them. Fix the end-stop bar's foot to the panel beside the post so the bar runs in front of the lever and under the arm, ending short of the platter's rim, with the TPU-sleeved pin standing 45 mm from the arm pivot; with the arm swung by hand, the tube must meet the sleeve before the stylus reaches a radius of about 53 mm.

Screw the deck camera bracket low on the end panel at platter height, 30 mm inside the panel, 20 mm to the front, 155 mm up, facing the headshell across the platter, with the LED bar housing beside it aimed low across the platter surface. Run the Camera Module 3 ribbon and the LED wires out through a hole in the panel.

Plug the 6.3 mm mono cable into the deck's remote start/stop jack. Open the deck, find the 33 and 45 button switches on the front-left board, measure the voltage across each with the deck on, and solder two thin wires across each switch's legs, led out through the case under the board. Close the deck. Nothing else in it is touched.

### 9. Electronics

Nothing is boxed. The parts sit on the outside faces of the frame panels, where they are reachable, cool and out of the record's space, in two groups joined by one USB cable. The CAD places every board and box at its catalogue size (`cad/parts/electronics.py`), and the two views below are rendered from it: the rear panel with the controller group, the pump and the X chain, and the deck-end panel with the Pi group.

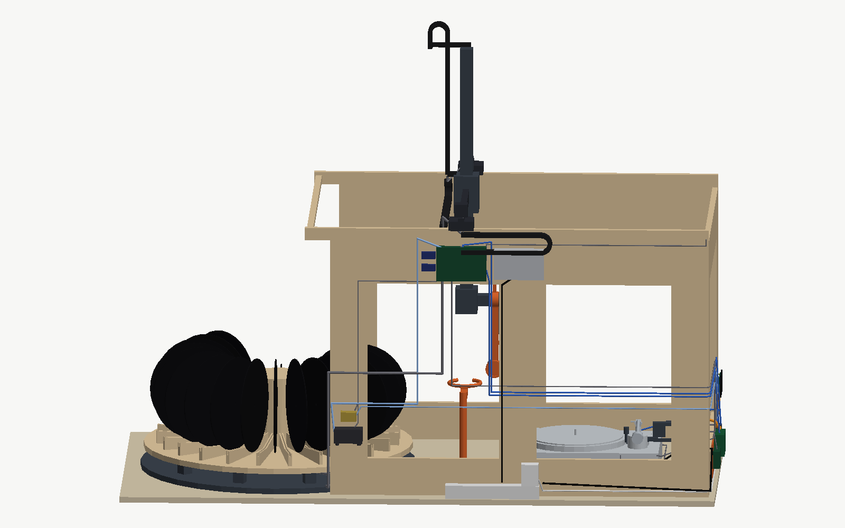
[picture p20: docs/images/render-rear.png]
The rear of the machine: the controller group under the X beam, the pump and valve near the open end, the X chain in its trough, the cables climbing the panel


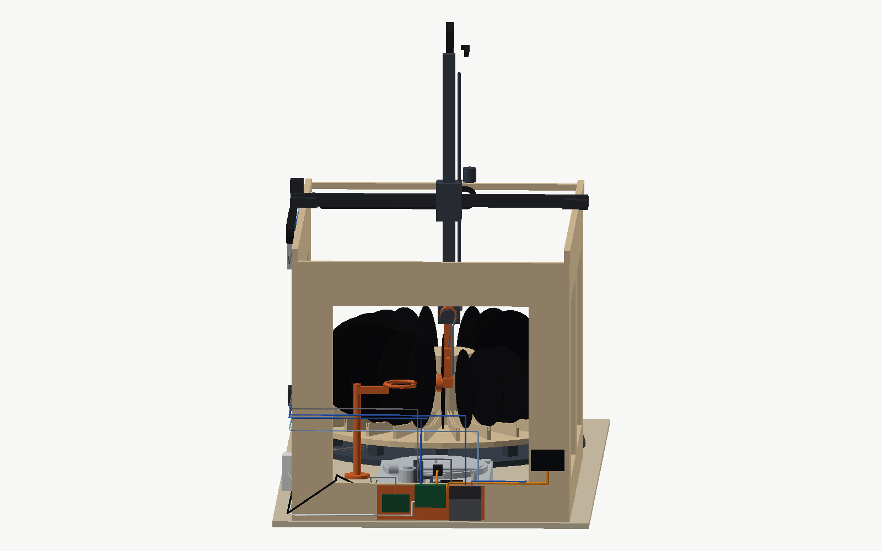
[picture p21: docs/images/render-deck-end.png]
The deck end of the machine: the Pi group on its plate outside the end panel, the Scarlett on the bench, the deck camera's ribbon through the panel


**Controller group, outside the rear panel, just under the X beam and centred on the X chain's fixed end at X ≈ 200 mm.** The Octopus on a printed plate on standoffs; the 24 V supply beside it, with its mains inlet fused and earthed; the 24 → 12 V buck for the pump, the valve and the LED bar; and the 24 → 5 V buck for the servo — the servo alone, never the Pi, because an MG996R stalls at about 2.5 A. Every cable to the gantry climbs 25 cm from here into the X chain instead of a metre up from a box on the bench, which takes most of a metre off every gantry cable.

**Pump and valve, outside the rear panel near the open end, at about X = −100 mm, on rubber mounts.** As far from the deck as the frame allows: a diaphragm pump is a vibration source, and the deck sits between X = 371 and 820. The hose runs along the outside of the panel to the chain anchor and up. The MPRLS is not here. It is an I²C device, and I²C does not like the 1.7 m to the Pi, but a vacuum line does not care about length: a tube stub tees off at the valve and runs to the sensor beside the Pi. The stub's 20 ml of dead volume is nothing against a 1 L/min pump.

**Pi group, outside the deck-end panel, low, beside the hole for the deck camera's ribbon.** The Pi on a printed plate in its aluminium shell with twin fans, the powered hub, the SSD, the relay card and the MPRLS; the Scarlett on the bench beside the deck. The Pi's official 15 W supply is a wall plug, so it stands in the power strip on the rear panel and its fixed 1.5 m USB-C lead runs along the panel and round the corner to the Pi. The status display sits on the panel's front post, where its 50 cm DSI ribbon reaches from the Pi with 9 cm to spare, angled so its light stays off the platter. The deck camera's ribbon is 30 cm through the panel, the relay card's cables into the deck about a metre, and the Pi's USB-C cable to the Octopus 2.2 m along the outside of the panels. Two mains supplies, one at each end, so a power strip runs along the rear panel.

Wire the five TMC2209 sticks into the Octopus with UART jumpers set, X, Y, Z, wrist and carousel in that order; the servo to the servo header; the pump, valve and LED to three fan or heater MOSFET outputs, the LED on a hardware PWM pin; every end-stop, the Hall sensor and the slot sensor to end-stop inputs. Set the TMC run currents in `printer.cfg` and nowhere else.

### 10. Cabling

Three cable chains, 10 × 20 mm, R28, not two: the concept drew one along the X beam and one along the column and forgot that the Y carriage moves 625 mm along the cross beam. The chain lengths below are half the travel plus the bend allowance plus 150 mm for the mounts, rounded up; the 3 m bought covers all three with a metre spare.

| Chain | Runs along | Travel it covers | Length |
|---|---|---|---|
| X | A trough on the rear panel's outer face just under the X beam, fixed end at mid-travel | 857 mm | 700 mm |
| Y | The −X side of the cross beam, fixed end at the rear X plate | 625 mm | 600 mm |
| Z | Standing above the guide block on the −X side of the column, fixed end on the block, moving end on a post on the column top | up to 600 mm | 600 mm |

The machine from the front with the chains and cables drawn: the X chain under the rear beam, the Y chain beside the cross beam, the Z chain standing above the guide block, the hose and camera cable down the arm

The CAD draws the three chains and the cables that feed them at the home pose, since their shape changes with every move; the collision sweep checks the electronics, the post on the column and the cable runs that ride rigidly on the column and the wrist, and leaves the chains out. Three placements came out of drawing them. The X chain cannot share the beam's outside face with the X motor, so it lies in a trough on the panel under the beam and the motor sits on the rear end bracket above it, where its lead is a hand's length from the chain's moving end; a motor on the front bracket would have needed its cable to cross the whole cross beam past the moving Y carriage. The Z chain stands up rather than hanging down: a chain hanging from the guide block beside the column would need 850 mm and would dip between the spokes at the pick, so it is fixed on top of the guide block and its moving end is a post on the column top, which puts its bend about 1.45 m above the bench at the top of the travel, where nothing else is. The gantry cables enter the column top, run down the column's −X slot under a cover, come out above the Z block, cross to the outrigger and enter the wrist hub; the hose and the camera cable then run down the +Y face of the arm, opposite the cup, so they never enter the ring rest's opening.

Everything to the gantry leaves the controller group on the outside of the rear panel, climbs 25 cm to the beam, enters the X chain, crosses to the Y chain on the cross beam, and, for anything on the column or the wrist, enters the Z chain. Dress each chain with its cables laid flat and not crossing, the vacuum hose on the outside of the bend, and a cable tie at each chain end only — nothing tied inside the chain.

**Cable lengths.** Each length is the routed path from where the cable starts — the controller group for anything Klipper drives or reads, the Pi group for anything the Pi drives or reads, the pump for the hose — to the device, with 15 % added and rounded up to the next 10 cm. The rule is that a cable which turns out too long is fixed with a cable tie and a cable which turns out too short is a new cable, so every number here errs long, and the loop that results is dressed into the chain. Where the bill of materials already names a length, the verdict says whether it reaches.

| Cable | Route | Buy | In the BOM | Verdict |
|---|---|---|---|---|
| Vacuum hose, pump to cup, 6 × 4 PU | Pump, along the rear panel to the chain anchor, X, Y and Z chains, arm to the cup neck, plus plumbing at the pump | 4.5 m | 7 m | Reaches |
| Tube stub, valve tee to the MPRLS at the Pi | Along the outside of the rear panel and round the corner | 2.1 m | in the 7 m | Reaches: 6.6 m of the 7 used |
| Wrist camera USB, C270 | Pi group's hub along the outside of both panels to the chain anchor, up the chains to the camera mount, 110 mm up the arm | 5.6 m | The C270's fixed 1.5 m | Does not reach, and past the 5 m passive USB 2.0 limit: an active 5 m repeater cable, 6.5 m in two legs with the C270's lead |
| Wrist stepper, 4-core | Controller group up the chains to the outrigger | 3.0 m | Geared motor's bare lead, 0.5 m | 2.5 m extension |
| Wrist Hall sensor, 3-core | Same as the wrist stepper | 3.0 m | Bare module | 3 m of 3-core |
| Z stepper, 4-core | To the guide block on the Y carriage | 2.1 m | Motor lead, about 1 m | 1.1 m extension |
| Z end-stop, 3-core | Same | 2.1 m | 0.5 m lead | 1.6 m extension |
| Y stepper, 4-core | To the cross-beam end on the X carriage | 1.3 m | Motor lead, about 1 m | 0.3 m extension, or mount the motor at the near end and use the lead |
| Y end-stop, 3-core | Same | 1.3 m | 0.5 m lead | 0.8 m extension |
| X stepper, 4-core | To the X carriage | 1.3 m | Motor lead, about 1 m | 0.3 m extension |
| X end-stop, 3-core | Fixed at the deck end of the X beam | 1.2 m | 0.5 m lead | 0.7 m extension |
| Deck camera CSI ribbon | Pi group through the panel to the bracket | 0.1 m | The camera's own 200 mm, and a 0.5 m spare | Reaches |
| Status display DSI ribbon | Pi group to the deck-end panel's front post | 0.41 m | 0.5 m | Reaches with 9 cm to fold |
| LED bar, 2-core 12 V | Controller group along the outside of the panels to the end panel | 2.3 m | Strip only | 2.3 m of 2-core |
| Cue servo, 3-core 5 V | Controller group to the end panel at lever height | 2.1 m | MG996R lead, 0.3 m | 1.8 m extension |
| Carousel stepper, 4-core | Controller group along the rear panel, down to the base plate | 2.6 m | Geared motor's bare lead, 0.5 m | 2.1 m extension |
| Carousel home sensor, 3-core | Same | 2.6 m | Bare module | 2.6 m of 3-core |
| Pump and valve drive, 2 × 2-core 12 V | Controller group along the rear panel to the pump mount | 1.0 m each | — | 2 m of 2-core |
| Pi supply, USB-C | Wall plug in the power strip, along the rear panel and round the corner to the Pi | 1.2 m | The official supply's fixed 1.5 m | Reaches, if the plug sits in the strip's end sockets |
| Pi to Octopus, USB-A to USB-C | Pi group along the outside of the panels to the controller group | 2.2 m | — | Buy a 3 m USB-A to USB-C cable; the extra is a tie |
| Deck remote start/stop, 6.3 mm | Relay card to the deck's rear jack | 1.2 m | 1.8 m | Reaches with 60 cm to tie up |
| 33 and 45 button taps, 2 × 2-core thin | Relay card into the deck's front-left board | 1.4 m each | Thin wire | 3 m of 3-core, two cores used |

The extensions add up to about 7 m of 4-core for the steppers, 15 m of 3-core for the sensors, the servo and the button taps, 4 m of 2-core for the LED, the pump and the valve, an active 5 m USB repeater, a 3 m USB-A to USB-C cable and 7 m of tube. The Z chain then carries the hose, the USB cable, the 4-core and the 3-core side by side at about 19 of its 20 mm: full, so nothing more goes into it later. Silicone 20 AWG is the right wire for the steppers, the servo and the 12 V loads; the sensors can take 24 AWG.

### 11. Power-up and commissioning

Power the Octopus alone first, no motors connected, and flash Klipper. Connect one stepper at a time and jog it a few millimetres in each direction at low current before connecting the next; a stepper wired backwards is found here and nowhere worse. Home each axis by hand against its end-stop and set the soft limits in `printer.cfg` from what the ruler says, not from the CAD, then confirm that the Z hard limit stops the column above its lowest working height.

Power the Pi from its own supply, with the hub, and bring up Moonraker, the orchestrator and the web interface. Calibrate the datums through the interface with the cameras live, in this order: the pick slot's centre, the spindle, the ring rest, the arm pivot, and the arm's rest, lead-in and run-out angles for the deck as measured. Run the cycle in step-through mode with no record, then with a sacrificial record, then with a good one, and only then a batch.

The collision sweep in `../cad/check_collisions.py` runs against the CAD, not the machine. Every number that a ruler changed on the real deck goes into `../cad/params.py` first, the sweep runs, and only a clean sweep is allowed to become a soft limit.

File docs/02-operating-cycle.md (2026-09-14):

# Operating cycle

One record goes through fourteen steps. The concept model animates each of them, and the order of the axis moves within each step is the order the controller will use, not an approximation.

The cycle below is rendered from the CAD model along the planner's own keyframes, for a 12" in slot 0 with the carousel's mixed demonstration load around it; the same cycle for a [10"](images/cycle-10.png) and a [7"](images/cycle-7.png) differs only in how deep the wrist descends at the pick and the return. `cad-model.html` plays all three interactively.

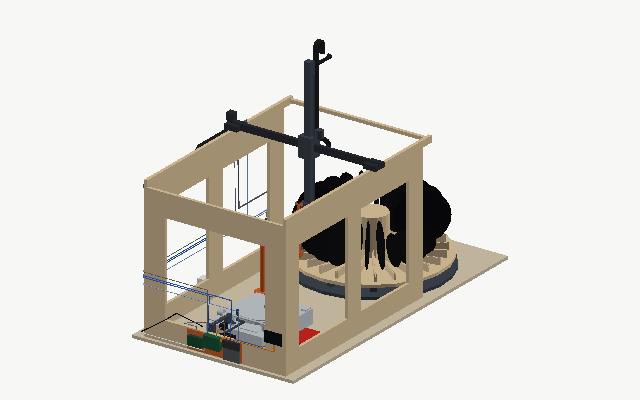
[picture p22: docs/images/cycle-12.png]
The cycle for a 12" record, rendered from the model: pick, place, cue, play, lift, flip on the ring rest, place side B, return, index


## Before a batch

The user brushes each record by hand and loads up to 24 of them into the carousel and enters the batch manifest in the web interface: one line per slot with size (12", 10" or 7"), speed (33 or 45), and flags for reverse-play or locked-groove sides; a line can also say "by hand" for a record the carousel cannot present (see below). The machine homes every axis, indexes the carousel to slot 1, and checks with the wrist camera from above that a record is present where the manifest says one is and that its spoke has the length its size implies, so a wrong size is caught before the pick. The manifest editor refuses a 12" in the slot on the front side of a 7": the wrist descends beside that spoke, 62 mm deeper for a 7" than for a 12", and a 12" there would be in its way (`05-design-decisions.md`). A 7", a 10" or an empty slot there is fine, so a run of 7"s costs one empty slot. A batch can also be run one side at a time (see below), which the manifest records so that the second run knows which side it is recording.

## The steps

**1. Pick from carousel.** At travel height the gantry positions the wrist above the gap beside the spoke at the pick position. The arm descends into the gap to the centre height of the record's size, with the cup 8 mm from the record's face, then moves along Y onto the label; vacuum on, the pressure sensor confirms the seal, and the record lifts straight up out of its slot. Spokes never touch. The record's centre is known: every size rolls to the apex of the V floor in its comb, so the radius is fixed and the height follows from the manifest's size; no camera is involved here.

**2. Place side A.** The vertical record leaves the carousel along X at travel height, passes beside the flip station, and only when it is over the deck does the wrist turn to −90° so the record is horizontal, cup on top. It is lowered to a few millimetres above the mat, centred over the spindle, and released; the spindle tip enters the hollow cup and does the final centring. The wrist then hovers over the platter with the cup pointing down and the wrist camera photographs the label, finds the centre from the spindle, and measures the lead-in and run-out radii of this side.

**3. Lift arm, engage fork.** Nothing is spinning yet; the cue-lever servo raises the arm on the deck's own damped lift. The fork descends from above and straddles the finger lift while the arm still sits over its rest.

**4. Carry arm to lead-in.** The fork walks the floating arm along its arc to the lead-in radius measured in step 2. The deck camera confirms the headshell's position.

**5. Lower needle, start.** The fork rises clear. The cue lever lowers the stylus onto the stationary lead-in groove; the deck camera confirms contact. Start is tapped. Recording on the Scarlett has already been running for a few seconds, so nothing is lost; the lead-in silence absorbs the spin-up.

**6. Run-out: stop, lift, find arm.** The recording's silence detector and the deck camera's headshell radius both indicate the run-out. Stop is tapped first, then the cue lever lifts the arm. The camera tells the gantry where the headshell actually is, which can be anywhere on the surface, and the fork descends onto the finger lift there.

**7. Carry arm to rest, lower.** The fork walks the floating arm back over the rest, rises clear, and the cue lever sets the arm down.

**8. Lift record off the platter.** Cup onto the A-side label from above, vacuum on, straight up off the spindle.

**9. Carry to station, B up.** Over the deck the wrist first swings the record to vertical, the carriage moves in Y to the station's line, and only then does the wrist swing on to B-up, so the record never sweeps past the frame's front panel. The gantry carries it to the station and lowers it until its label rests on the ring; the arm enters through the ring's opening.

**10. Release and withdraw.** Vacuum off. The cup drops straight down clear of the ring. Nothing else moves. The record stays on the rest by its label.

**11. Re-grip from above.** The arm backs out 185 mm along Y from under the record, rises, hangs straight down, crosses along Y to the far side of the station, swings to cup-down and comes down onto the B-side label. On the way in the wrist camera photographs label B; the groove radii of side B are measured over the platter in step 12.

**12. Place side B.** As step 2. Steps 3 to 7 then repeat for side B.

**13. Return to its slot.** Over the deck the wrist turns back to 0°, the record hangs vertical, travels along X beside the station and is lowered into the slot it came from. Vacuum off, the cup backs away along Y, the arm rises out of the gap.

**14. Index carousel.** The stepper turns the magazine one slot. The next record is at the pick position.

## Motion planning rules

Every move between two poses is a list of waypoints, one axis at a time, generated by a planner with these rules. The planner lives in `cad/kinematics.py`, its output is `cad/cycle.json`, and `cad/check_collisions.py` sweeps it against the CAD model.

Retreat first. If the previous pose left the cup against or under something (a spoke face, a record on the ring), the first move is a short retreat along the approach direction.

Raise to travel height. The wrist pivot travels at 54 cm above the bench: high enough that a vertical record clears the carousel's combs and the station ring's neighbourhood, and a horizontal record clears everything.

Order the horizontal moves by direction. Leaving the carousel the order is X, then Y, then wrist; heading towards it the order is wrist, then Y, then X. This keeps a vertical record moving in its own plane while it is between spokes, and only turns the wrist over the deck, where there is room to swing.

Lower, then approach. The final descent stops a few millimetres short and the last movement is a slow approach along the tool's axis.

Station poses have their own plans, because the arm has to get out from under a record before it can rise.

Every target position is either a fixed mechanical datum (the pick slot, the spindle, the ring rest, the arm rest) or a camera measurement against one. Nothing is inferred from how many records are left or how far something moved last time. The one thing the planner takes from the manifest is the record's size, and it changes only the pick and the return, by the height of the record's centre in its slot: the platter and the ring rest take every record at its centre, so steps 2 to 12 are the same for a 7" as for a 12".

## Records placed by hand

The carousel locates a record by its round edge, and the pick assumes the label at the centre of that circle. A shaped picture disc (a sawblade, a heart, a star) has no round edge to roll on, and a disc whose outline is not centred on its hole comes to rest at a height nobody can predict; the cup could hold either by its label, but the machine could not find the label. A manifest line marked "by hand" therefore skips the carousel: when the batch reaches it the gantry parks, the platter stopped, and the interface asks the user to lay the record on the spindle. From "continue" the machine does what it does for any other record: the wrist hovers over the platter and photographs and measures the side, the arm is carried to the lead-in, the side is recorded, and the arm is returned to its rest. Then it parks again and asks the user to turn the record over, and after side B to take it off. Its slot in the carousel stays empty. The same mode serves a record that is too precious to be picked, or a 10" or 7" that the user would rather not stand in a slot.

## One side per run

A batch marked "one side per run" skips steps 9 to 12: each record is picked, placed, recorded, lifted and returned, and nothing is set down on the ring rest or re-gripped. The user then turns every record in its slot, which takes about two minutes for 24, and starts the second run; the records are in the slots they came from, so the second run's manifest is the first one's with the side changed. The wrist camera photographs the label of the side being played over the platter in both runs, so both labels are still captured, and the orchestrator compares the second run's photo with the first run's: a record that was not turned shows the same label and is skipped and reported rather than recorded twice. The mode exists as the fallback the decision log describes, and as the mode the machine runs in while the re-grip is being commissioned; it halves what one unattended run can do, from both sides of 24 records to one.

## Timing

A side runs 10 to 25 minutes depending on the record. The handling between sides adds about a minute and a half, so one record takes 25 to 55 minutes and an eight-hour run digitises roughly 10 to 20 records; a full 24-slot carousel therefore covers a long day or a weekend.

## Fault handling

The rule is that the machine never tries to be clever with a stylus in a groove.

A skip is detected two ways at once: a discontinuity in the recorded audio and a jump in the headshell radius on the deck camera. Either one triggers the response: the cue-lever servo lifts the arm within half a second, without waiting for the gantry, stop is tapped, the batch pauses, and the user is notified. There is no automatic retry. The web interface offers a manual "retry from here" after the user has looked.

The end-stop pin on the cue-servo bracket means that even if the software fails entirely, the arm cannot swing past the run-out onto the label.

A lost vacuum seal during a carry is seen by the orchestrator, which polls the pressure sensor throughout every carry, and stops all motion within about a tenth of a second and holds position; the record, if it dropped, is at most a few centimetres above a surface designed to receive it, and the state is reported.

A missing record, a record of the wrong size for its manifest line, or a hole the camera cannot find at the pick position skips that slot and reports it.

Any Klipper error (a stall, an end-stop hit outside homing) halts the machine in place; the orchestrator lifts the arm via the cue lever if a side was playing, and reports.

Before every cue the X, Y and Z axes are re-homed, so a lost step earlier in the cycle cannot carry over into a move near the stylus. Lateral moves with the fork engaged are only ever made with the cue lever up.

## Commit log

2026-09-06 Add concept design: interactive model, README and design docs
    Concept phase of the AutomaticRecordDigitalizer: an interactive 3D
    model of the record changer stepping through the full operating cycle,
    a README with the project description, and detailed documents under
    docs/ covering the design specification, the operating cycle and fault
    handling, electronics and software, the bill of materials with German
    sources, the design-decision log and the open questions for the first
    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
2026-09-06 Specify the Omnitronic DD 3120 as the deck
    Name the Omnitronic DD 3120 (cue lever, remote start/stop jack, pitch
    output) as the turntable and the Stanton T.92 USB as the spare; use the
    remote start/stop jack instead of tapping the button, note the Ortofon
    DJ S cartridge, and add the jack behaviour, the pitch output and the
    stylus choice to the open questions.
    Claude-Session: https://claude.ai/code/session_01Px9ubKUzjB6m54gnPGhbCV
2026-09-06 Apply the DD 3120's measured layout
    Measure spindle, arm pivot, arm rest and cue-lever positions from a
    top-down photo of the deck (added under docs/images), move the arm and
    controls in the model accordingly, put the cue-lever servo on the frame's
    end panel with a short pusher since the lever sits 3 cm from the deck's
    right edge, and note the slipmat, the 78 rpm setting and the quartz lock.
    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
2026-09-06 Describe the remote start/stop jack correctly
    It is a 6.3 mm fader-start input from the era of mixers and hi-fi systems
    that started the deck when the fader came up; it only starts and stops
    the platter and has no influence on speed.
    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
2026-09-06 Simplify: drop the brush, V-slot on X/Y, donor printer
    Remove the brush module (records are brushed by hand before loading),
    run X and Y on 2040 V-slot with Delrin wheels and keep a rail only on Z,
    add a donor-printer section to the bill of materials, and record why an
    automatic turntable was rejected (locked grooves, inside-out records,
    non-standard start and end positions).
    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
2026-09-06 Use a relay board for the deck's start/stop jack and speed buttons
    Three dry-contact relay channels replace the optocouplers: one on the
    6.3 mm remote start/stop jack, two soldered across the 33 and 45 button
    switches, driven from the Octopus so the stop path stays in the Klipper
    queue with the cue-lever servo.
    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
2026-09-06 Reuse the Conrad USB relay card and the MIMXRT1010-EVK
    The Conrad 393905 (CP210x GPIO relays, driven from the Pi via the cp210x
    gpiochip or crelay) switches the remote start/stop jack and the 33/45
    buttons; the MIMXRT1010-EVK can serve as a second Klipper MCU for the
    carousel stepper, servo, LED, pump, valve and sensors when a donor
    printer board runs the gantry axes, replacing the Octopus.
    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
2026-09-06 Rule out the MIMXRT1010-EVK as a Klipper MCU
    Klipper's i.MX RT port does not support the RT1011; a Raspberry Pi Pico
    takes the second-MCU role when a donor printer board runs the gantry.
    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
2026-09-06 Record the current state and bring all documents in line
    Add docs/07-status-and-next-steps.md (state of the concept, decisions in
    order, parts on hand, build order), fix the README's throughput claim,
    and remove stale references to the brush, linear rails, optocouplers and
    the Octopus-only controller across the other documents.
    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
2026-09-06 Add parametric CadQuery CAD, motion planner and collision checker
    cad/ holds the machine as CadQuery code: every dimension is a named
    parameter in params.py, the parts are envelopes of the sub-assemblies,
    kinematics.py plans the fourteen-step cycle as keyframes (cycle.json),
    and check_collisions.py sweeps the moving parts against the environment
    by boolean intersection. The sweep passes with zero intersections at
    20 mm / 5 degree sampling. STEP files of the whole machine and the
    sub-assemblies and STL files of the first printed parts are in
    cad/export/.
    The first sweep found five conflicts the concept model had not shown;
    the resulting changes (frame 86 cm wide, fork 55 mm, end stop at 45 m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
    [assembly_place.step, assembly_regrip.step, carousel_base.step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]
2026-09-07 Add Dependabot and status badges
    Dependabot watches the three places this repository pins a version: the
    actions in .github/workflows/, CadQuery in cad/requirements.txt, and the base
    image and features in .devcontainer/devcontainer.json. Weekly, with the
    actions grouped into one pull request so a quiet week stays quiet. Its pull
    requests run the same ruff, markdownlint and collision checks as any other.
    The README gains badges for CI, the documentation build, Dependabot and ruff.
    The Dependabot badge is a static one linking to the configuration, not a
    workflow badge: the dependabot/dependabot-updates workflow does not exist
    until Dependabot has run once, and its badge URL 404s until then.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
2026-09-07 Show the machine in the documentation, from the CAD
    The repository already had a WebGL model and the site already served it, but
    nothing linked to it: README named concept-model.html in a code span, so the
    published page had no clickable path to it at all.
    Linking it as it stood would have published wrong geometry. The concept model
    carries its own constants in centimetres while cad/params.py is the authority
    in millimetres, and the two have diverged: the frame reads 80 cm there against
    FRAME_Y = 430 (86 cm) in the CAD, and the 6 cm is precisely the widening the
    collision checker forced so the fork clears the rear panel at the re-grip pose.
    The fork itself went 100 -> 55 mm and the end-stop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
2026-09-13 Absorb the September 2026 sourcing pass
    Every line of the bill of materials was priced against live German shop pages
    on 10 September 2026, and the machine now runs on a Raspberry Pi 4B rev 1.1 /
    2 GB already on hand rather than a Pi 5. The estimate of 865 EUR survived in
    aggregate only because it was the sum of two large errors in opposite
    directions.
    Bill of materials:
    - The cue-lever servo was wrong by 10x. No sub-30 EUR linear servo is stocked
    anywhere in Germany or the EU; the cheapest verified are 90,95 and 123,49
    EUR. An MG996R at 6,65 EUR on the printed pusher rod already in the parts
    list does the job - a bracket change, not a design change.
    - The vacuum switch went the othe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
2026-09-14 Add assembly instructions and fix what the BOM check found
    docs/08-assembly-instructions.md: cut list with window sizes and sheet
    nesting, the Baumarkt list, every printed part with quantity, material and
    whether the CAD has it print-ready or as an envelope, the parts already on
    hand and where each goes, the assembly order by dependence, and every cable's
    routed length from the electronics box with 15 % wiggle room. Too long is a
    cable tie; too short is a new cable.
    Checking the bill of materials against cad/params.py and the planner's real
    travel found the concept's 80 cm frame surviving in three cut lengths after
    the CAD widened it to 86: the 2040 cross beam (800 -> 940), the 2020 tie
    (80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
2026-09-14 Electronics on the frame, not in a box
    Decision from review: the electronic parts do not need a box and can sit on
    the frame. That resolves the open question about the box's size, and the deck
    camera ribbon problem with it.
    Layout, in 08-assembly-instructions.md and the decision log: the controller,
    the supply and both bucks on the outside of the rear panel just under the X
    beam, centred on the cable chain's fixed end, so every gantry cable climbs
    25 cm rather than a metre - the riser drops from 981 to 250 mm and every
    gantry cable shortens by about 0.7 m. The pump and valve on the same panel
    near the open end, on rubber mounts, as far from the deck as the frame allows.
    The Pi with its USB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
    [assembly_place.step, assembly_regrip.step, station.step]
2026-09-14 Ring rest at the label's edge, with an O-ring on top
    Decision from review: the ring may touch the record outside the label; it
    should be smaller so it holds a 7" properly, with room for the cup, and a
    rubber on top for stability.
    The ring is now 100 mm in mean diameter with a 6 mm section: contact between
    44 and 56 mm from the record's centre, the edge of the label. A 7" overhangs
    it by 32 mm instead of 2, the cup has 16 mm to the inner edge, and the 60 deg
    opening is 44 mm wide at the inner edge, 10 mm a side for the 24 mm arm. The
    groove on top is cut for a 3 mm O-ring standing 1 mm proud, and the record
    rests on that, not on the print; ST_PAD carries the millimetre into
    record_on_ring an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
    [assembly_place.step, assembly_regrip.step, station.step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]
2026-09-14 Vacuum sensing on the Pi, the grip check in the orchestrator
    Decision from review: stay with the MPRLS alone. The seal check becomes an
    orchestrator step and the latency is accepted and written down.
    03: the controller's end-stop inputs no longer list a vacuum switch; the
    sensor is an MPRLS on the Pi's I2C bus. GRIP leaves the Klipper macro list
    (PUMP_ON stays) and becomes a step in the orchestrator: pump on, poll the
    sensor to the seal threshold with a timeout, keep polling at 20 Hz or better
    through every carry, emergency stop through Moonraker on loss. The abort is
    one poll interval plus one round trip, under a tenth of a second, and the
    pressure at grip and release is logged with each s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
2026-09-14 Hold 10" and 7" records in the carousel
    The concept promised every size and the CAD delivered a 12": the rim ring it
    drew touched nothing, and the pick was hard-wired to a 12" standing on the
    disc through its comb. Each comb's slot floor is now a V, 5 degrees each way,
    with its apex at the pick radius, so a record of any diameter rolls to the
    same centre line and only its centre height follows its size. The rim is gone.
    The planner takes the record's radius (only the pick and the return move),
    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
    [assembly_place.step, assembly_regrip.step, carousel_comb.stl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]
2026-09-14 Put the electronics, chains and cables into the model, render views for the docs
    cad/parts/electronics.py places every board and box at its catalogue size
    where 08-assembly-instructions.md puts it: the controller group under the X
    beam, pump and valve near the open end, the Pi group outside the deck-end
    panel, the Scarlett and the power strip on the bench. The three cable chains
    and every cable and hose run are drawn as tubes along their routes; the
    chains and their feed cables at the home pose, since their shape changes
    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
    [assembly_place.step, assembly_regrip.step]
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2026-10-03 Absorb the 3 October sourcing re-check
    Every priced line of the shopping list was fetched again on 3 October
    2026 and the list regenerated from the sourcing study: the Octopus and
    the plain 17HS4417P1 are discontinued at roboter-bausatz, the lines the
    September errata added are in at last, and a Hornbach sheet prices the
    Baumarkt items and the wood.
    The design documents follow it: plywood at its real price (a birch sheet
    for the panels, MDF for the discs), a 4.3" DSI status display, an active
    5 m USB repeater for the wrist camera, 7 m of 4-core and 15 m of 3-core,
    record identity taken from the manifest, and the open question of what
    catches a mis-loaded magazine in place of the 720p label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
2026-10-04 Build the panels in OSB 3, with steel where OSB is weak
    Decided on 4 October 2026 in the sourcing study: two shelf-stock OSB 3
    sheets replace the birch sheet on a five-week store order. Steel takes
    what OSB does badly: an angle down each inside corner for the edge
    joints, M4 T-nuts for every part that comes off again, penny washers
    under the M5 beam bolts. The discs stay MDF. The Hornbach sheet drops
    from 362,81 to 226,89 EUR and the estimate from about 1187 to 1051 EUR.
2026-10-04 Put the measured deck outline and spindle position into the model
    Measured on the DD 3120: 44.9 x 35.1 x 8.6 cm, the spindle 17.9 cm from
    the left edge and 17.4 cm from the rear. The photo had 45 x 36 x 9 and
    18.4 / 18.6. The plinth top drops 4 mm, and everything that stands on
    the deck or reaches for it follows: the arm pivot, the arm rest, the
    cue lever, the servo, and the end-stop bar and pin are now heights
    above the plinth instead of fixed numbers.
    Collision sweep: 1299 samples, 0 collisions. Exports, cycle.json, the
    web scene, the renders and the animations are regenerated.
    [assembly_place.step, assembly_regrip.step, deck_interface.step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]
2026-10-04 Raise the platter to its measured 18 mm
    The platter stands 1.8 cm above the case top, not the 15 mm assumed, so
    the mat top and every place and lift height rise by 3 mm. Confirmed with
    it: 8.6 cm is from the feet to the case top, and 17.4 cm is from the
    rear edge.
    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
    [assembly_place.step, assembly_regrip.step, deck_plinth.step]
2026-10-04 Place the arm pivot and the cue lever as measured; hang the servo over the lever
    Measured on the deck: the arm pivot 69.5 mm from the right edge and
    93.5 mm from the rear, and the cue lever's top 40 mm from the right
    edge, travelling 24 mm front to back as it lifts the arm. A pusher rod
    along X from the end panel cannot move a lever that travels along Y, so
    the MG996R now hangs from a beam over the lever, shaft vertical, with a
    yoke on its horn around the lever's top.
    The arm angles are computed from the pivot and the stylus radii instead
    of typed in, and the arm rest follows the pivot. The end-stop bar moves
    in front of the lever and no longer reaches inside the platter's rim.
    Collision s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
    [assembly_place.step, assembly_regrip.step, deck_interface.step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]
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2026-10-10 Put the status display, the Pi's shell and its wall-plug supply in the CAD; base plate 18 mm, mat 4 mm
    - params: CAR_BASE_T 18 to match the MDF it is cut from, with CAR_DISC_Z
    following it, so the disc and every pick height sit 3 mm higher; MAT_T 4
    for the cork mat; a Pi-shell and display block, the sizes marked MEASURE.
    - electronics: display_group() on the deck-end panel's front post, joining
    the static electronics the sweep checks; the Pi at the Armor shell's size;
    psu_pi as a wall plug in the power strip with cable_pi_power round the
    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
    [assembly_place.step, assembly_regrip.step, carousel_base.step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]
2026-10-11 Mark the 7 October orders as bought
    The Conrad, cnc-zubehoer and welectron orders have arrived. Their rows in
    the shopping list are now owned at 0,00 €, cnc-zubehoer and welectron
    leave the shipping tables, and the bought cnc-zubehoer chain replaces the
    Dold CK10 rows on the fewest-suppliers and donor routes.
    The USB-A to USB-C cable for the Octopus stays open: the Conrad invoice
    carries a Lightning-to-USB-A cable instead. It is now the only Conrad line
    and pays 4,95 € shipping. Conrad's prices were 20 € above the 3 October
    re-check; the notes record what was paid.
    Routes now 840,58 / 743,45 / 557,92 € delivered. docs/04, docs/07, the
    README status and the corrections log follow.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
2026-10-11 Fix the build on the donor route and bring every document to it
    The controller is the donor's Creality 4.2.x board for X, Y, Z and the
    wrist, with a Raspberry Pi Pico as Klipper's second MCU for the carousel
    stepper, the servo, the pump, the valve, the LED and the home sensors;
    the Octopus stays priced as the fallback. docs/03 describes the two-MCU
    setup, docs/05 records the decision, docs/08 wires and commissions it,
    docs/06 opens the one question it raises.
    Checking the donor route against an Ender 3 V2: the Z coupler and the
    corner brackets come from the donor; the belts, a third idler and a third
    pulley do not. That pulley needs an 8 mm bore - the geared motor's shaft
    is 8 mm, which eve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
2026-10-11 Add Amazon for the small parts on every route
    At the owner's request: everything Reichelt carried (jack lead, LED strip,
    MOSFETs, heat shrink, inserts, micro-USB leads, pump buffers; the Mean
    Well supply and the Conrad USB-C lead on the Octopus routes) and the
    pneumatic consumables (tube, fittings, tee, O-ring, taking druckluft's
    9,90 EUR cut-length surcharge with them) move to Amazon. Reichelt and
    Conrad leave the sheets; druckluft keeps the valve and the nipple.
    One parcel fewer and Prime delivery, not a saving: Amazon sells in packs
    where Reichelt sold singles, so the donor route rises about 10 EUR to
    555,29 EUR delivered. All Amazon rows are estimates. docs/04, docs/07 and
    the correctio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
2026-10-11 Look up every Amazon row and link the listings
    All 35 Amazon rows (11 on the donor route, 12 on each Octopus route) were
    searched on amazon.de in Chrome: each now links its listing by ASIN, carries
    the price shown and is Prime; the notes name the cheaper or plainer
    alternative seen beside it. Two parts changed: the deck's remote lead is a
    solder-type 6.35 mm mono plug on the 3-core wire on hand, as the bill of
    materials always said, and the Octopus routes' supply is the genuine Mean
    Well at 19,95 EUR.
    Donor route 560,35 EUR delivered (was 555,29 on estimates). docs/04, docs/07
    and the corrections log follow.
    Claude-Session: https://c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
2026-10-11 Open every link in Chrome: fix four, take over drifted prices, motors to Amazon
    All 76 links on the donor route and the Hornbach sheet were opened in
    Chrome. Fixed: the Dold stub shaft (parentheses broke the Markdown link),
    the Dold bracket link (category), the two roboter-bausatz search links
    (now the 8 mm pulley and the sleeving), the dead Saugeranschlussnippel link
    (FGN 016 18 I, 3,14 EUR, on request) and the StepStick-breakout estimate
    (no such product; a perfboard and female headers instead).
    roboter-bausatz prices updated, mostly up (Nutensteine 0,47 EUR). Oyostepper
    raised the geared motor to 37,02 EUR and charges 15,27 EUR shipping, so the
    donor route takes the same STEPPERONLINE mo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
2026-10-11 Cup nipple from Amazon: druckluft-fachhandel cannot supply it
    The FGN 016 18 I is on request only, so the same Riegler part (314.018,
    G 1/8 female, 7-25 mm cups) comes from Blumenbecker on Amazon at 2,95 EUR
    plus a 5,55 EUR marketplace parcel; druckluft keeps the valve alone. The
    Riegler 42 mm silicone bellows cup is noted as the fallback if the printed
    lip fails. Donor route 590,35 EUR delivered.
    Claude-Session: https://claude.ai/code/session_01Qg3YCizFyzL9qJvHLe6eCg
2026-10-11 Right-size the slot hardware and add the missing Z column
    One pack of M5 T-head bolts instead of five and 25 slide-in nuts instead
    of 50: the build drops about 25 bolts into slots and bolts the two X beams
    to the panels with 16 nuts, and the Ender 3 V2 brings its own slot
    hardware. Counting them found the Z column on no sheet: the CAD draws a
    760 mm 2040 profile carrying the MGN12 rail, docs/08 bolts the rail to it,
    but docs/01 and 04 had taken the rail for the column. A 760 mm cut joins
    the Dold order and M3 spring-ball T-nuts fix the rail. Donor route
    589,09 EUR delivered.
    Claude-Session: https://claude.ai/code/session_01Qg3YCizFyzL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
2026-10-17 docs: seal the vacuum cup around the centre hole with a second lip
    The cup is concentric with the record's 7.24 mm centre hole, which is open
    on the far side at every grip (comb, ring rest, spindle), so a plain cup
    cannot hold vacuum. Record the fix: a two-lip printed cup with an inner lip
    of about 14 mm around the hole and a blind centre pocket for the spindle
    tip. Outer envelope unchanged, so params.py and the collision sweep stand.
    Claude-Session: https://claude.ai/code/session_016UdqwwY7Q4rjdZpSNejxya
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2026-10-19 Cup seats the record on three pads; the lips only seal
    Two soft lips seal but leave the record's plane to wherever they settle,
    and it moves under load. Three short TPU pads between the lips, 120 deg
    apart, take the record once the vacuum pulls it down. Recorded in the
    decision log, with the gripper description, the hand-pump test and the
    printed-parts row brought to it.
2026-10-19 Bring the documents up to what has been bought
    A consistency check of the documents against the shopping list's
    deliveries. The status pages still listed the extrusion, motors, rail
    and pneumatics as not bought and said nothing had been cut; the
    panels and discs were bought cut to size, so there is no OSB offcut,
    and the second MDF piece is 680 x 880 on the receipt, too small for
    the 860 disc. Also brought to what was bought: the glue (Ponal D2,
    2 x 120 g), the printed cup in place of a bought one, the geared
    motors' supplier, the rail price, the deck camera's own 200 mm ribbon,
    the O-ring's source, the remote jack lead and the wire for the
    steppers. The record centre heights in docs/08 foll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
2026-10-19 Gearmotor data sheet: 17HS15-PG5, 57:11, up to 3 deg backlash
    The drawing in the motor's box names it the 17HS15-1684S-PG5, the
    short-bodied variant, which explains the 39 mm body. Its gearbox is
    57:11 rather than 5:1, so the carousel is about 175:1, not 170:1, and
    Klipper takes gear_ratio: 57:11. It allows up to 3 deg of backlash,
    up to 11.5 mm at the cup, which becomes an open question. The torque
    figures give a first estimate for the wrist question: about three
    times the static load. The motor is about 87 mm long overall, which
    does not fit upright under the carousel disc; that is recorded in
    the status, and the fix is a design decision still to take.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
2026-11-06 Lock the CAD dependencies and tighten what CI may run
    SonarCloud findings S8541, S8544, S6505 and S8233. cad/requirements.in now
    names what the CAD needs and cad/requirements.txt is the lock compiled from it
    with hashes. pip installs wheels only, markdownlint-cli2 installs without
    lifecycle scripts instead of through npx, and the Pages workflow grants its
    write permissions to the deploy job alone.
2026-11-06 Split the collision sweep and use literals for the poses
    SonarCloud findings S3776, S1542 and S7498. No change in behaviour:
    cad/cycle.json regenerates byte for byte and the sweep still reports 1301
    samples and 0 collisions.
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2026-11-06 Warn about a 12" on a 7"'s front side, and say which slot that is
    The rule was only stated in passing, as a "front side" nobody could find on the
    carousel, and the documents did not say what breaking it does. It now has a
    warning in the operating cycle and the commissioning step, and is defined by
    pick order. The manifest editor checks only what was typed, so a camera check
    of the neighbouring slot is a new open question. Also corrects the decision
    log's claim that the 7" is swept between 12" neighbours.
2026-11-06 Run the SonarCloud scan from CI
    A sonarcloud job in ci.yml scans with the SONAR_TOKEN secret, configured in
    sonar-project.properties. It skips pull requests from forks and Dependabot, which
    do not get the token, and pins the scan action to a commit because the action is
    handed the token. SonarCloud's Automatic Analysis has to be off for it to run.

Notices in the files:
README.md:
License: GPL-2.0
